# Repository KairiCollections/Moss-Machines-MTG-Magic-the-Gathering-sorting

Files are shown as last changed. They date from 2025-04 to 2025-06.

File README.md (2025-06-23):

# Moss Machine - Open Source Magic: The Gathering - MTG - Sorting & Recognition

<p align="center">
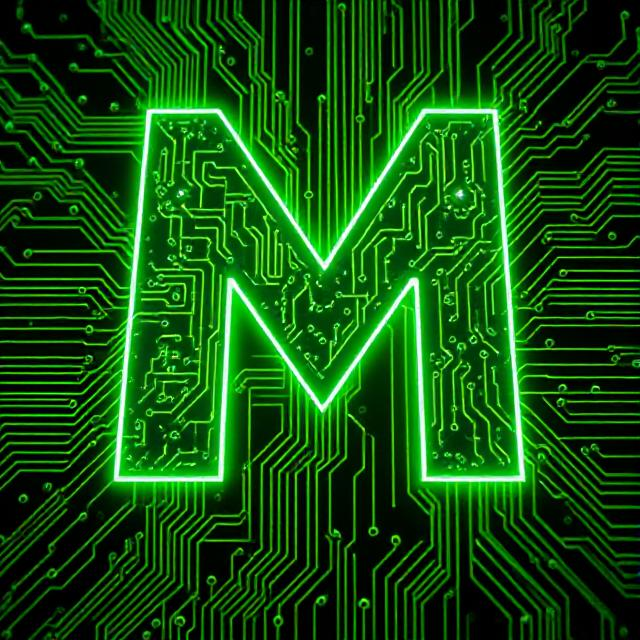
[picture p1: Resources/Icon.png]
  
</p>

Welcome to the Moss Machine project! This open-source initiative provides a comprehensive system for automating the sorting, recognition, and management of Magic: The Gathering (MTG) cards, with potential expansion to other Trading Card Games (TCGs).

---

### Overview

The Moss Machine combines computer vision, machine learning, and hardware integration to create a reliable, customizable card sorting solution. Whether you're a collector, player, or developer, this project offers tools and guidance to build your own automated card sorting system.

---

## Features

- **Open Source & Community Driven**  
  Fully open source code with transparent development. Contributions and modifications are encouraged—please credit the original source when creating derivatives.

- **Versatile Recognition Methods**  
  - Uses OpenCV for precise card detection and perspective correction at any angle.  
  - Employs advanced contour detection for accurate boundaries even in imperfect lighting conditions.  
  - Implements image hashing techniques for quick identification against a database of known card images, including color channel separation (RGB) for improved accuracy.  
  - Integrates Tesseract OCR for secondary verification through text recognition (e.g., card names).

- **Sorting & Organization**  
  - Multiple sorting modes based on card attributes such as color, mana value (CMC), type, set, and market value brackets.  
  - Supports flexible system configurations, including set grouping and custom filters.  
  - Special "buy mode" for evaluating purchase decisions based on price thresholds, helping collectors maintain budgets.

- **Hardware Integration**  
  Designed to interface with physical sorting hardware via serial communication, configurable for different bin layouts and rejection mechanisms.

- **Performance & Logging**  
  - Detailed timing logs for each processing stage.  
  - Robust multiple attempt strategies for reliable name detection and image matching.  
  - Excludes digital-only and promotional sets for focused collection management.

- **Configurable & Extensible**  
  - Centralized configuration files for all settings.  
  - Adjustable thresholds for matching accuracy.  
  - Easy modification of sorting logic and set filters.

- **Technology Stack**  
  - Python: OpenCV, Tesseract OCR, ImageHash, PySerial, YOLO (Ultralytics), Pillow, NumPy, JSON, Scikit-Image  
  - C++: Arduino control and decision-making  

---

## Pictures
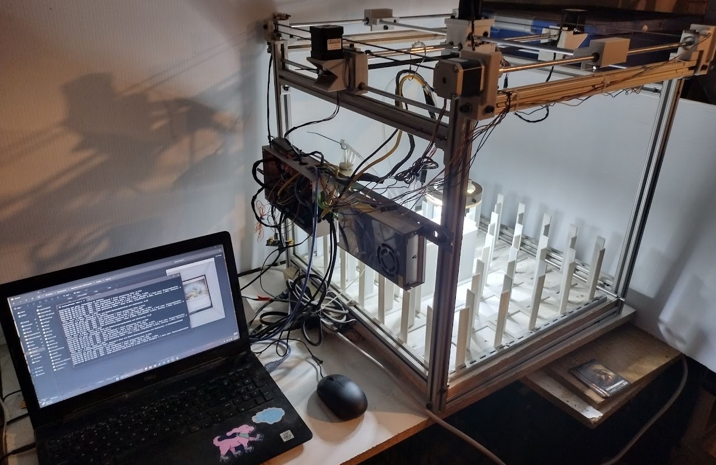
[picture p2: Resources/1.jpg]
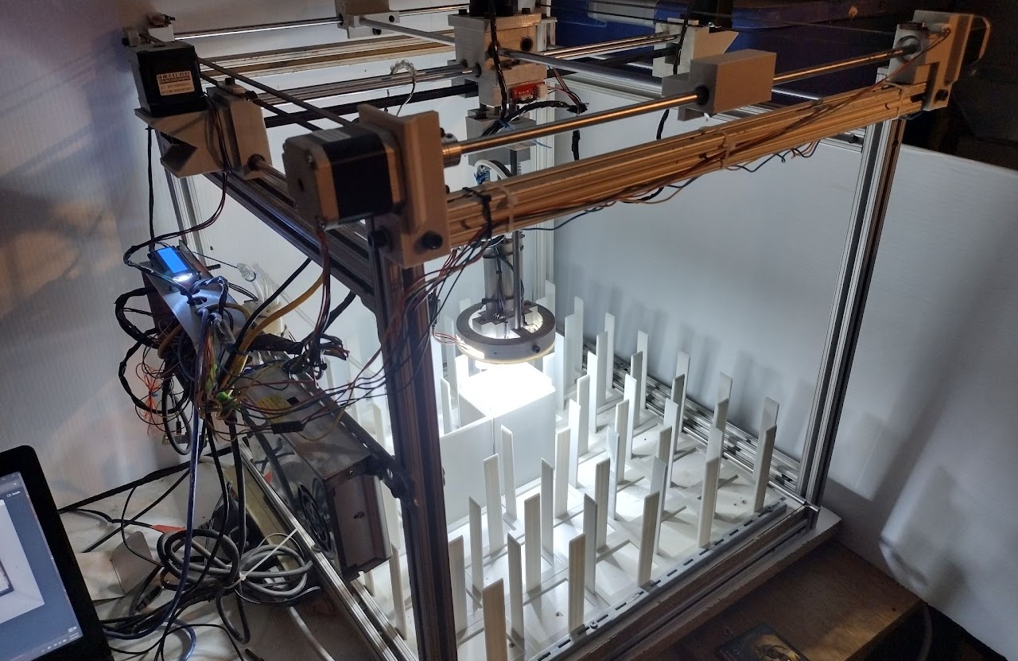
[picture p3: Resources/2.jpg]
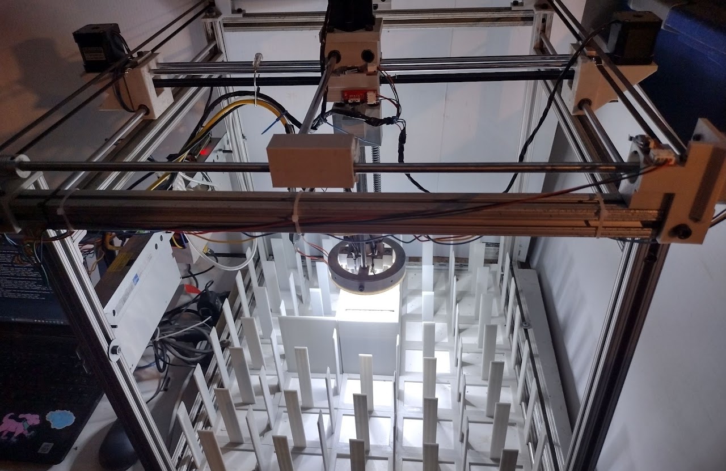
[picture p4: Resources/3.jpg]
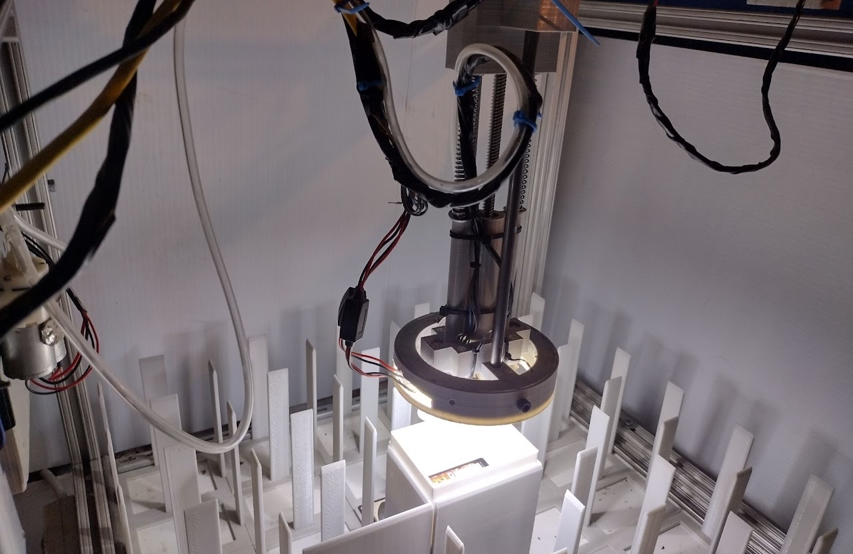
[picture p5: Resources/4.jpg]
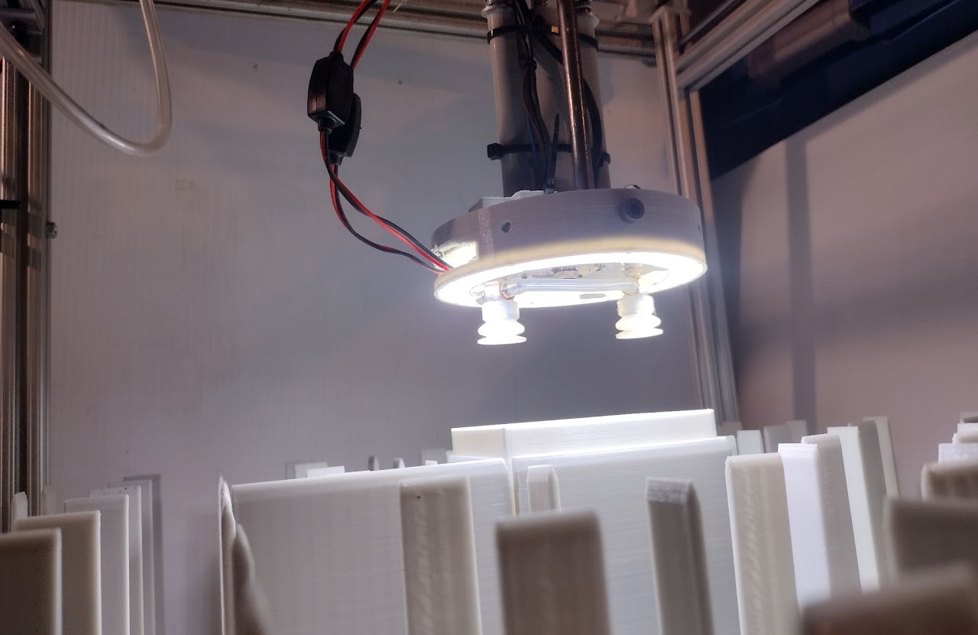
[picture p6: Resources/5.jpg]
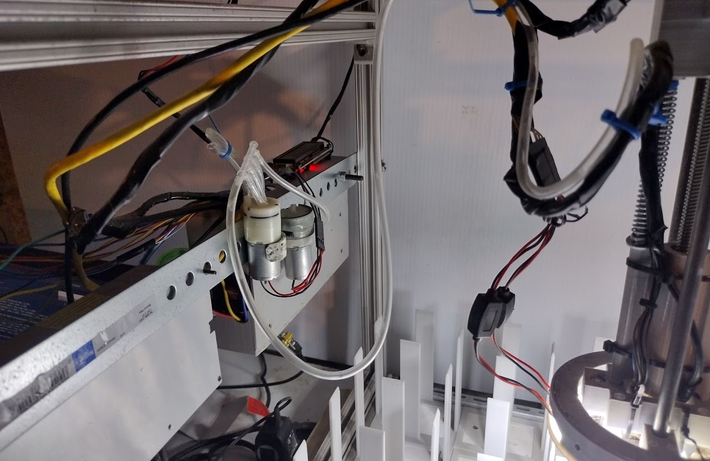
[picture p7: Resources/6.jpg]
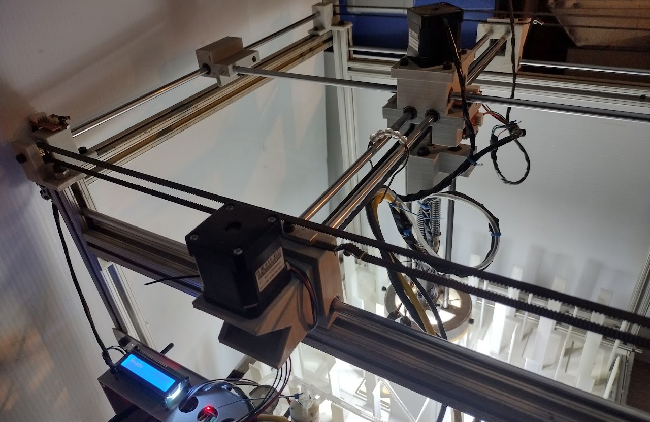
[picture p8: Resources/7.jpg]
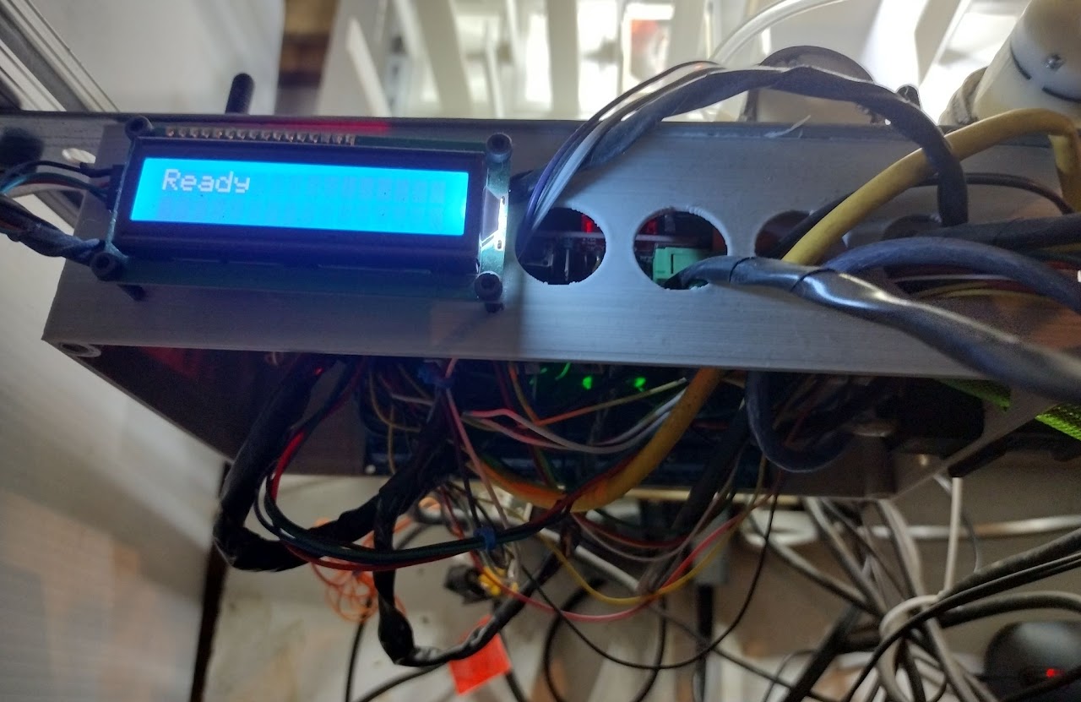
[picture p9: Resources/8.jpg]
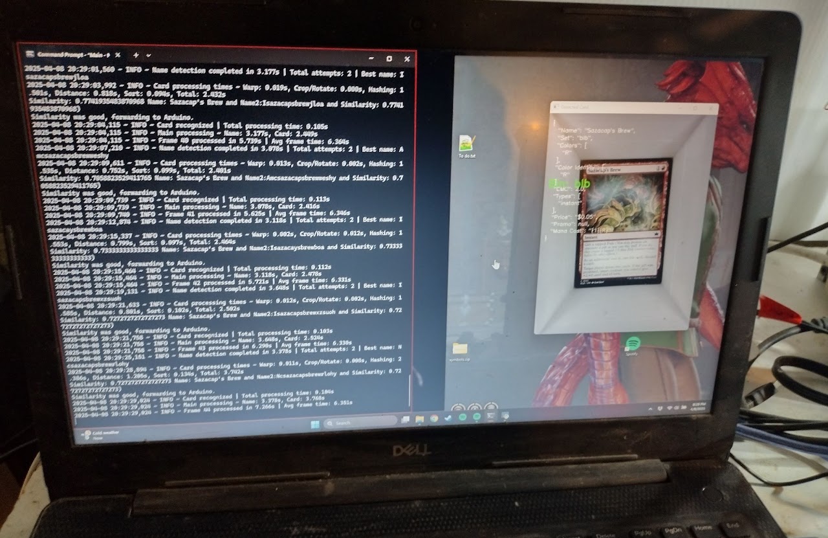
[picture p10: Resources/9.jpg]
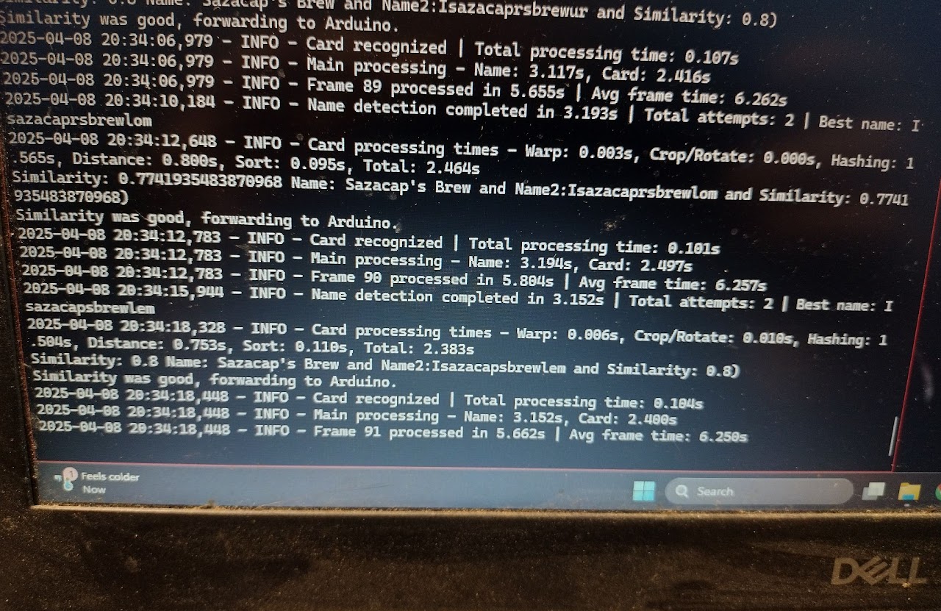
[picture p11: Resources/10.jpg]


---

### Disclaimer

- The project is open source and may evolve significantly over time.  
- All code is thoroughly tested but may require calibration based on your hardware setup.  
- Use caution—never put valuable cards in the machine without testing.  
- If you modify or create your own variations, please credit the original source.

---

## Build Your Own

### Get Started
- All necessary files, including code, 3D print files, and hardware schematics, are available in this repository.
- Follow the detailed instructions within the Discord under #assembly

---

## Legal & Usage Notice

**Disclaimer:**  
This system is intended for hobbyist and educational use. Always test with non-valuable cards first. Handle valuable or rare cards with care—never trust automated sorting in critical scenarios. The project is open source; use at your own risk.

---

## Connect with Us & Follow

| Discord Logo | Reddit Logo | GitHub Logo |
|:---:|:---:|:---:|
| **Join our Discord:**<br>[https://discord.gg/2gNWpV6UjW](https://discord.gg/2gNWpV6UjW) | **Reddit:**<br>[r/MossMachine](https://www.reddit.com/r/MossMachine/) | **Repository:**<br>[GitHub](https://github.com/KairiCollections/Moss-Machine---Magic-the-Gathering-recognition-and-sorting-machine) |

---

## Support
Help keep my motivation and my wife less annoyed with the machine's existence
- Patreon - https://www.patreon.com/KairiCollections
- By me a coffee - https://www.buymeacoffee.com/KairiCollections
- Ko-fi - http://ko-fi.com/kairiskyewillow

Other non-related support:
- https://www.etsy.com/shop/KairiCollections

---

## Acknowledgments & License

This project is licensed under the **Creative Commons Attribution-NonCommercial-ShareAlike 4.0 International License (CC BY-NC-SA 4.0)**.  
Please give credit to the original authors when creating derivatives.

---

**Happy Sorting & Recognizing!**  
*Build smarter, organize better, and enjoy your collection to the fullest!*

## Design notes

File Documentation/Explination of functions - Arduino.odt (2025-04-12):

Moss Machine Arduino code

This code controls an automated card sorting machine that uses stepper motors, relays, suction cups, vacuum pumps and a VL6180X distance sensor to pick up and sort cards into different trays based on input from a python script running on a computer.

Main Components and Functions

Hardware Control

- Stepper motors for X, Y, Z axis movement

- Relay-controlled vacuum system for card pickup/release

- VL6180X time-of-flight distance sensor for card detection

- I2C LCD for status display

- Endstop switches for homing/calibration

Core Functionality

- Receives sorting commands via serial communication

- Moves cards to designated trays based on input

- Tracks card counts per tray

Adjustable Variables and Their Functions

Movement Parameters

const short initial_pickup_distance | Initial Z-axis movement distance for pickup
const short initial_drop_distance | Initial Z-axis movement distance for drop
const short Xcal | X-axis movement multiplier (steps per unit)
const short Ycal | Y-axis movement multiplier (steps per unit)
const short RZM | Z-axis range-to-movement scaling factor

Speed Settings

const short speed | Base movement speed (higher = slower) for X/Y axes
const short zspeed | Z-axis movement speed during pickup
const short zespeed | Z-axis movement speed during return

Thresholds and Limits

const short pickup_threshold | Minimum distance reading to consider card picked up
const short release_threshold | Minimum distance reading to confirm card released
const short HCC | Homing Cycle Count - rehome after this many operations
const short YCourseCorrection | Y-axis correction steps after movement
const short XCourseCorrection | X-axis correction steps after movement
const float timeout | Communication timeout value
const short buffSize | Serial input buffer size

Tray Configuration

short CountArray[35]; | Tracks card count in each tray (indices 1-34 used)
String AssignedTrayValue[35]; | Stores what each tray is assigned to sort

Key Functions Explained

Homemachine()

- Calibrates the machine by moving each axis until endstops are triggered

- Establishes known home position

- Called periodically (based on HCC) to maintain accuracy

pick(short steps, byte Release)

- Handles card pickup and release

- Uses vacuum relays to pick up cards

- Implements retry logic if pickup fails

- Release parameter determines if picking up (0) or releasing (1)

Tray(short var)

- Main sorting function that moves cards to specified tray

- Calculates X/Y coordinates based on tray number

- Manages pickup, movement, and drop sequence

- Updates tray counters

Move4() and Move1()

- Coordinate multi-axis movements

- Control stepper motor direction and step timing

- Implement precise positioning

DetermineAction()

- Parses incoming commands

- Routes to appropriate tray handling based on input

- Supports special commands like calibration

ReadRange()

- Gets distance measurements from VL6180X sensor

- Used to verify card pickup/release

- Also reads ambient light level (Lux)

ForLoop()

- Manages tray assignment logic

- Finds available trays for incoming cards

- Handles overflow conditions

Safety and Error Handling

Endstop Monitoring

- Regularly checks limit switches to prevent over-travel

- Used for homing/calibration
- ***Currently not being used during active operation*** if an error occurs and it “goes off the rails” turn off the machine. It will make noise but it will not damage anything. This will be enabled later

Sensor Error Detection

- Comprehensive VL6180X error status checking

- LCD feedback for sensor issues

Timeout Handling

- Automatic overflow tray routing if no commands received

Pickup Retry Logic

- Multiple attempts if card pickup fails

- Machine stop if persistent failures

Overflow Protection

- Stops machine if overflow tray reaches capacity (375 cards)

Communication Protocol

- Uses serial communication with start/end markers (< and >)

- Simple command structure (e.g., "tray1", "RejectCard")

- Status messages sent back to host ("<Arduino is ready>")

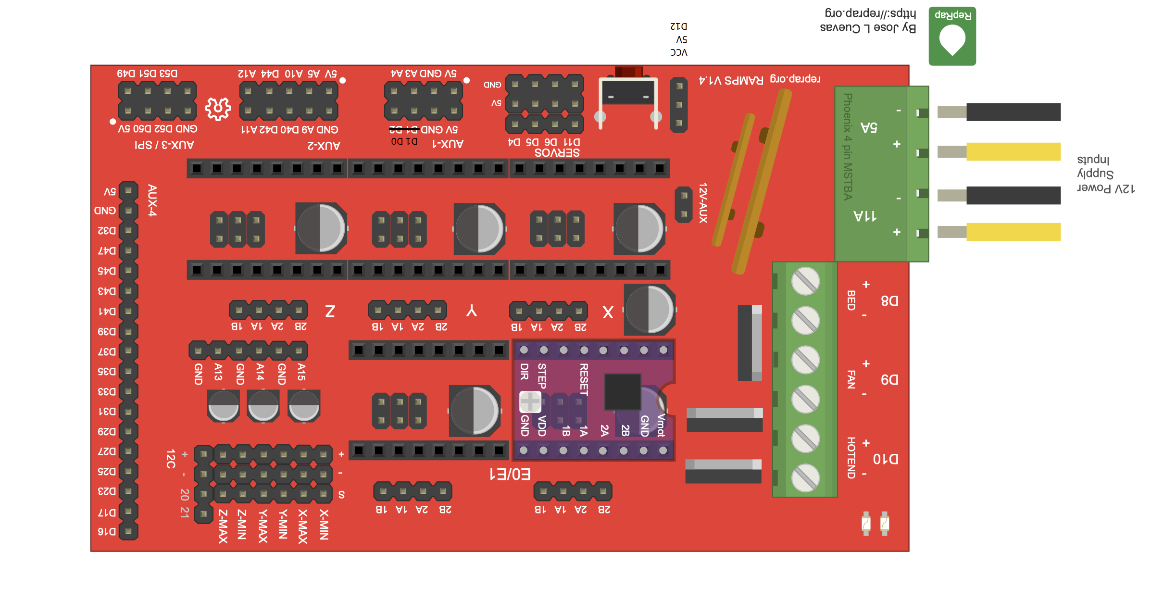
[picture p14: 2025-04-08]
Blueprints and diagrams/Ramps 1.4 Pinout.png

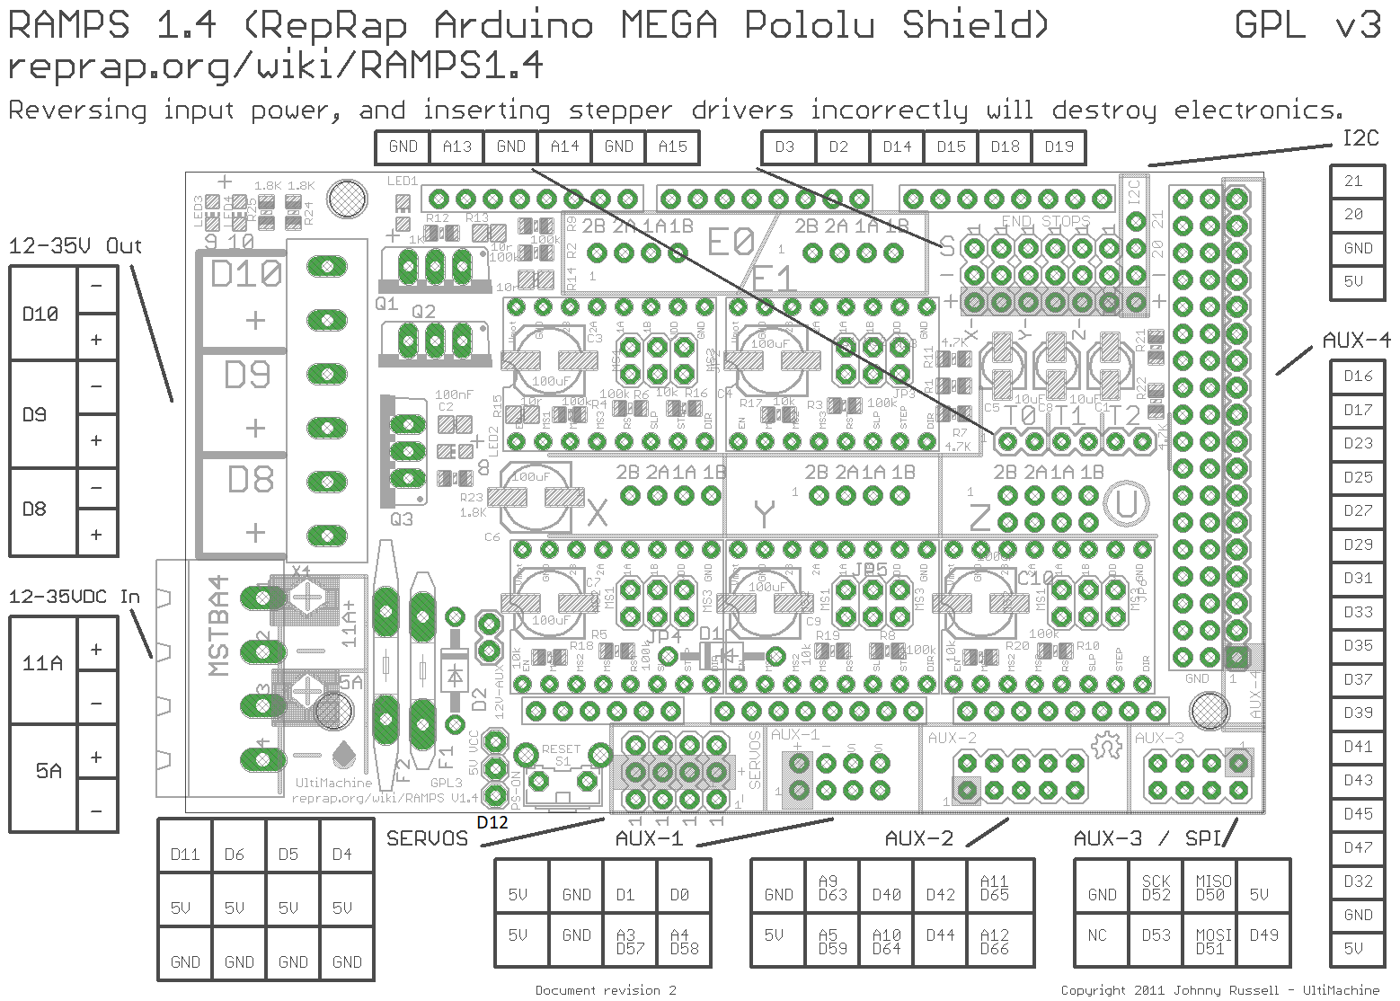
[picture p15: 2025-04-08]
Blueprints and diagrams/Ramps 1.4 Schematic 1.png

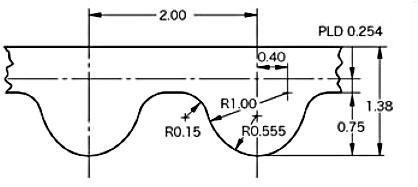
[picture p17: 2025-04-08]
Blueprints and diagrams/GT2 Belt.jpg

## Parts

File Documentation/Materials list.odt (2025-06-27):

Magic the Gathering

sorting machine materials

(If link is dead let me know)
Obviously these are just link recommendations, if you find a better deal go for it!

2525 Frame

Items | URL | Quantity
25x25x550mm Aluminum t-slot bar | https://www.amazon.com/IXGNIJ-Aluminum-Extrusion-25mmx25mm-European/dp/B0CR5P392H/ Cut to lengths (Trying to find a cheaper source, the 2020 frame is overall cheaper by about $90 on the complete build) | 6
25x25x500mm Aluminum t-slot bar | | 8
25x25 t-slot corner brackets | https://www.amazon.com/Connector-Aluminum-Extrusion-Bracket-Extruded/dp/B0B8H43B8X/ | 1

2020 Frame

Items | URL | Quantity
20x20x550mm Aluminum t-slot bar | https://s.click.aliexpress.com/e/_ooVn7JZ | 6
20x20x500mm Aluminum t-slot bar | | 8
20x20 corner brackets | https://s.click.aliexpress.com/e/_opvcbMQ | 1

Components

Items | URL | Quantity
M6 t slot nut (lot of 20) should work for either frame | https://s.click.aliexpress.com/e/_opiADM7 | 1
550mm x 8mm milled steel rods | https://www.amazon.com/550mm-Linear-Motion-Printer-Machine/dp/B09P87GC3X/ or https://s.click.aliexpress.com/e/_okMx702 or https://www.amazon.com/dp/B0B2LPDSMC/ | 6 rods total
2x 500mm x 8mm milled steel rods | | 2 rods total
2x 300mm x 8mm milled steel rods | | 2 rods total
12v 20A Power supply | https://s.click.aliexpress.com/e/_on92Pan | 1
12v Halo lights: 100mm and 110mm (white, comes in packs of 2 so you will have extras) | https://s.click.aliexpress.com/e/_omvoQvM | 1 each
Ardiuno Mega 2560 kit (Package B) | https://s.click.aliexpress.com/e/_oCAmKlH | 1
LCD1602 Blue I2C or LCD1602 Green I2C | https://s.click.aliexpress.com/e/_ol1EtsT | 1
Pulleys (5PCS, 20T W6 B5) | https://s.click.aliexpress.com/e/_oEcsqdb | 1
More pulleys (20T W6 B5) | https://s.click.aliexpress.com/e/_omv5y17 | 2
Belt clamps (lot of 3) | https://s.click.aliexpress.com/e/_omXSal3 | 1
6mm belt (5 meters) | https://s.click.aliexpress.com/e/_olDFNsd | 1
Belt tensioner springs | https://s.click.aliexpress.com/e/_oELpuTn
Time of Flight sensor (TOF050C) | https://s.click.aliexpress.com/e/_ontJu63 | 1
Power switch | https://s.click.aliexpress.com/e/_olikwcJ | 1
8MP USB camera (2 meter cable) | https://s.click.aliexpress.com/e/_olqvzqJ | 1
8mm screw rod - Pitch 2mm Lead 8mm, 300mm | https://s.click.aliexpress.com/e/_onu2dUo | 1
Endstops (you might break a couple during assembly, best to have extras) | https://s.click.aliexpress.com/e/_oljfq7t | 1
8mm bearings (LM8UU 10 pack) | https://s.click.aliexpress.com/e/_okaOZNY | 3
5mm to 8mm couplers | https://s.click.aliexpress.com/e/_oF5uLz0 | 3
Suction cups (Package 1) | https://s.click.aliexpress.com/e/_on9q31Y | 2
Vacuum pumps (300g option) | https://s.click.aliexpress.com/e/_oke1dk3 | 2
Hose splitter 2.4mm | https://s.click.aliexpress.com/e/_oEc8Vw2 | 1
Air line
Motors 17HS19-2004S1 – These are particularly strong motors for their size but rather they be strong vs weak (I used 42bhh48-151k-24b but a same size similar torque will work fine) | https://s.click.aliexpress.com/e/_onv5IFN | Need 5 (comes 3 per lot, will have 1 extra replacement motor
Hillman 1-3/8-in x 4-ft Interior/Exterior Zinc-Plated Steel Perforated (Need atleast 4 feet) | https://www.lowes.com/pd/Hillman-4-ft-x-1-375-in-Steel-Perforated/3059255 | 1
Hillman 10¼ in Zinc Gate Extension Spring 0.44 x 10¼ x 0.04 (11.10mm x 260.35mm x 1.05mm) | Lowes - Buy in store, website is confusing. UPC 008236801149 | 1
M6 thread x M8 shoulder x 100mm shoulder bolts | https://s.click.aliexpress.com/e/_oDGH8Bs | 2
M8x16x1 20 washers | https://s.click.aliexpress.com/e/_ole4eru | 1 lot (only need 2 of them)
Wires 18g wire (yellow and black) Can steal from an old PC power supply Bulk thinner wire (I mainly used recycled Ethernet and USB cables, lots of colors, nothing hair thin) but 26 awg will work fine | Recycle if possible but if not https://s.click.aliexpress.com/e/_ooCR0iT for both | A lot
Bolts, screws and nuts: 3mm x 10mm – 13 3mm x 15mm – 20 3mm x 20mm – 3 4mm x 10mm – 3 5mm x 15mm – 4 5mm x 30mm – 2 5mm x 5mm set screws – 6 6mm x 10mm – 12 6mm x 15mm – 2 6mm x 30mm – 4 6mm x 50mm – 4 #8 2-inch screws – 4 | | ?
M5 x 10mm tapered wood screws (48) | https://s.click.aliexpress.com/e/_oB0LquT | 5
Wood square – 550mm x 500mm x 25mm
Single shower curtain ring | Dollar tree | 1
Tip ties
Electrical tape or a wire management coil

3d printed stuff

Items | In GitHub | Quantity
Tray - 2 sides Tray - 3 sides W Tray - 3 sides T Tray - All sides Tray stabilizers: Tray mount - Middle Tray mount - Side Tray mount - Corners | | 24 6 4 1 24 20 4
X1, X2, X3, X4, Z1, Z2, Z3, Z4 (this model is duplicated to be 130mm long because of the shorter shoulder bolts. If you managed to get the 140mm bolts before the link died print the 90mm version), Z5, Light mount 1 and 2, Power switch case (2 pieces) Stabilizer / Y axis traveler | | 1 of each 2 of each
If using the 2020 frame: 2.5mm spacer 5mm spacer OR (M6x20x2.5mm 5 per lot) | https://s.click.aliexpress.com/e/_onpoScr | 24 4 7 lots (Need 32 washers)

Optional Substitutions

Items | URL | Replaces | Quantity
DIN rail main power supply (NDR-240-12V 20A) | https://s.click.aliexpress.com/e/_oETsD6e | 12v 20A Power supply | 1
DIN rail (50cm) | https://s.click.aliexpress.com/e/_o2B4oyA | Hillman 1-3/8-in x 4-ft Interior/Exterior Zinc-Plated Steel Perforated | 1
DIN rail mounts - 3d print - 3 files | In GitHub

Tools

Items | URL | Quantity
Volt meter (Needed to calibrate the main power supply to 12 volts) | (https://s.click.aliexpress.com/e/_olln5Pv) | 1
Dupont kit (SN-28B AND 1550PCS) | https://s.click.aliexpress.com/e/_oBtivTU | 1
Metric Allen wrenches (11Pcs Metric short) | (https://s.click.aliexpress.com/e/_op3MiA7) | 1
Small screwdriver kit | (https://s.click.aliexpress.com/e/_olUUvgb) | 1
Pliers | (https://s.click.aliexpress.com/e/_opsQM6L) | 1
Mini hammer (You don’t need a big smashy smashy hammer) | | 1
Drill | | 1
Drill bit set | | 1
6mm tap | Probably best to not buy from Aliexpress on this, get one local and high quality. You don’t want a cheap one to snap in the frame -_- | 1
Small piece of wood (2” square ish) for TAPPING bearings into 3d prints instead of hammering the bearing directly | | 1

Patreon - https://www.patreon.com/KairiCollections

By me a coffee - https://www.buymeacoffee.com/KairiCollections

Ko-fi - http://ko-fi.com/kairiskyewillow

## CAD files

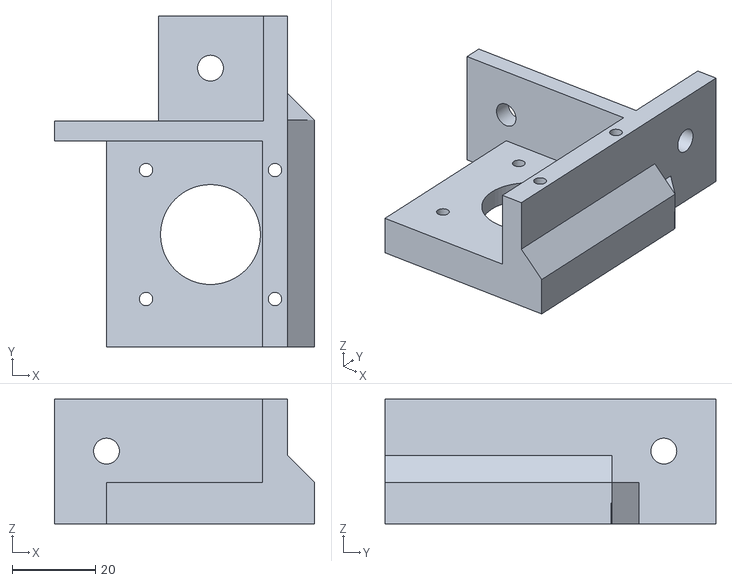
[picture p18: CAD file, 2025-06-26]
3D print/Axis/Axis - X/X motor mount 1.stl
62.5 x 79.5 x 30.0

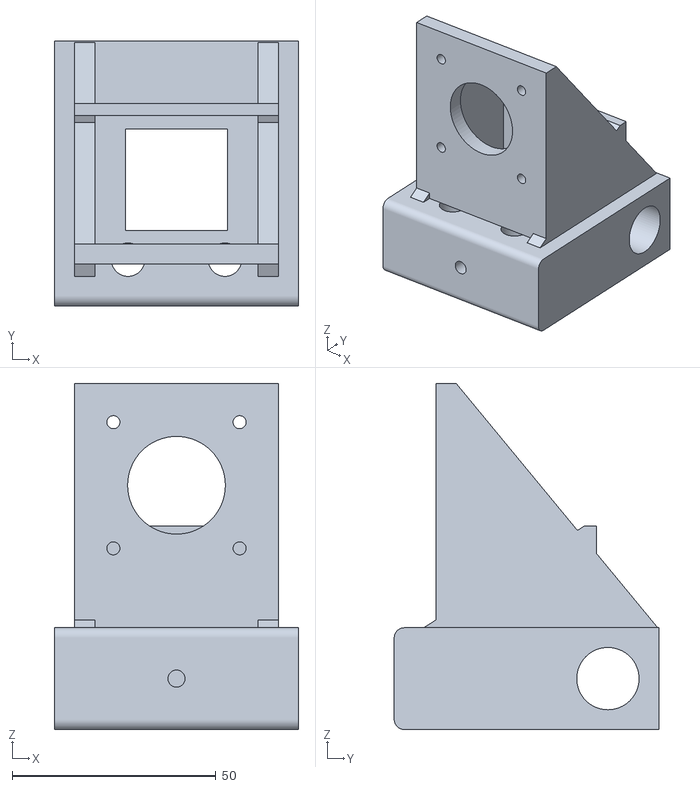
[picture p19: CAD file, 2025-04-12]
3D print/Axis/Axis - Y/Y - motor mount (Print 2).stl
60.0 x 65.0 x 85.0

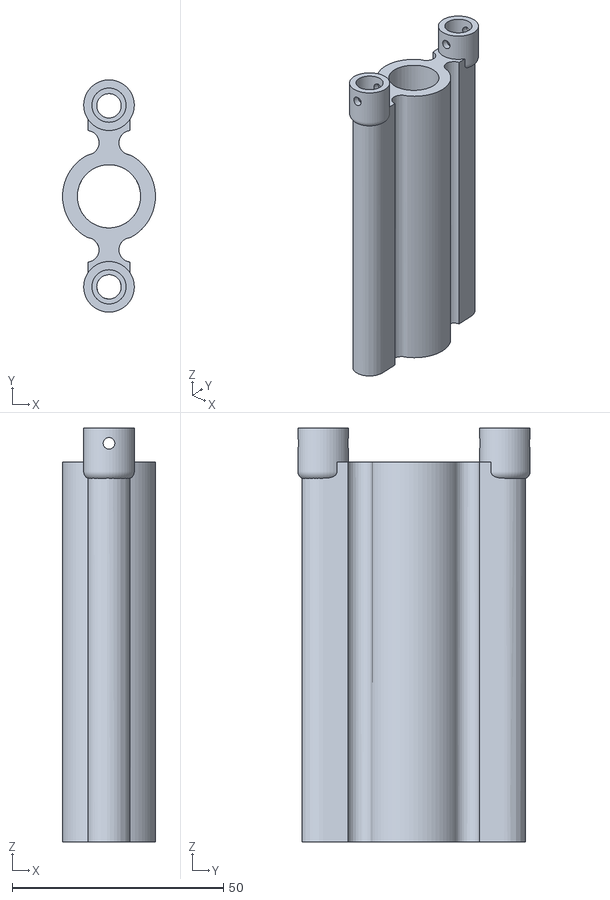
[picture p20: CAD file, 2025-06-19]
3D print/Axis/Axis - Z/Z4 - Extension - Option 2.stl
22.0 x 55.0 x 98.0

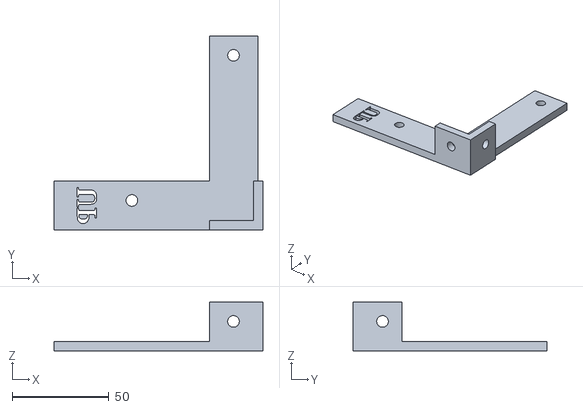
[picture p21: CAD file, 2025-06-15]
3D print/Drill guides/2020/Drill guide 1.stl
108.0 x 100.2 x 25.2

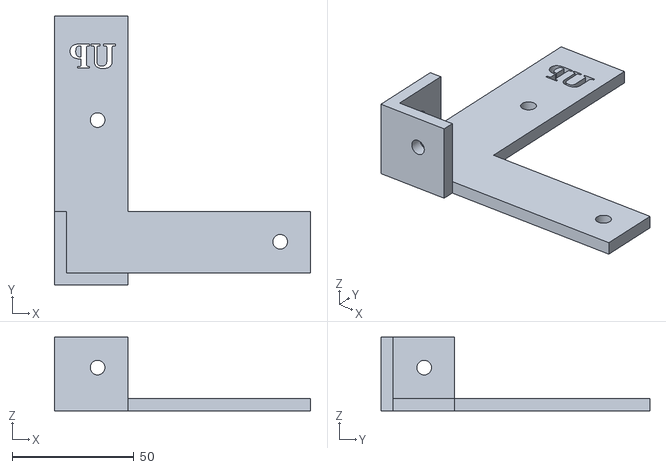
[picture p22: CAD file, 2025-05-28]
3D print/Drill guides/2525/Drill guide 2.stl
105.2 x 110.5 x 30.2

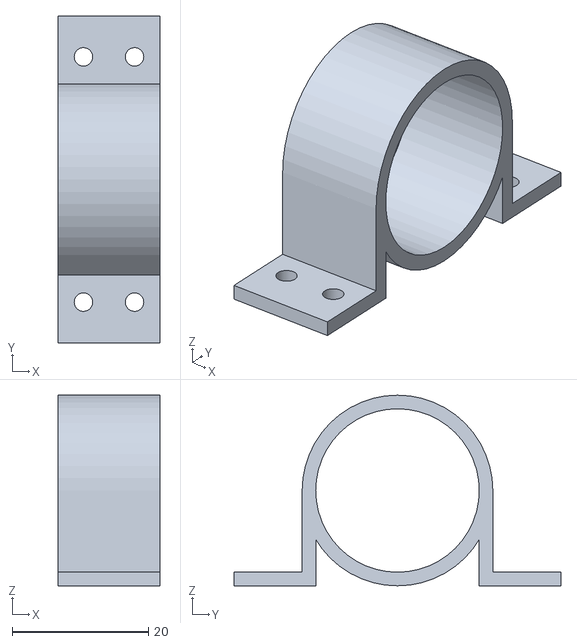
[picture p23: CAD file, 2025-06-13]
3D print/Electrical/Din rail options/Vacuum mount.stl
15.0 x 48.0 x 28.0

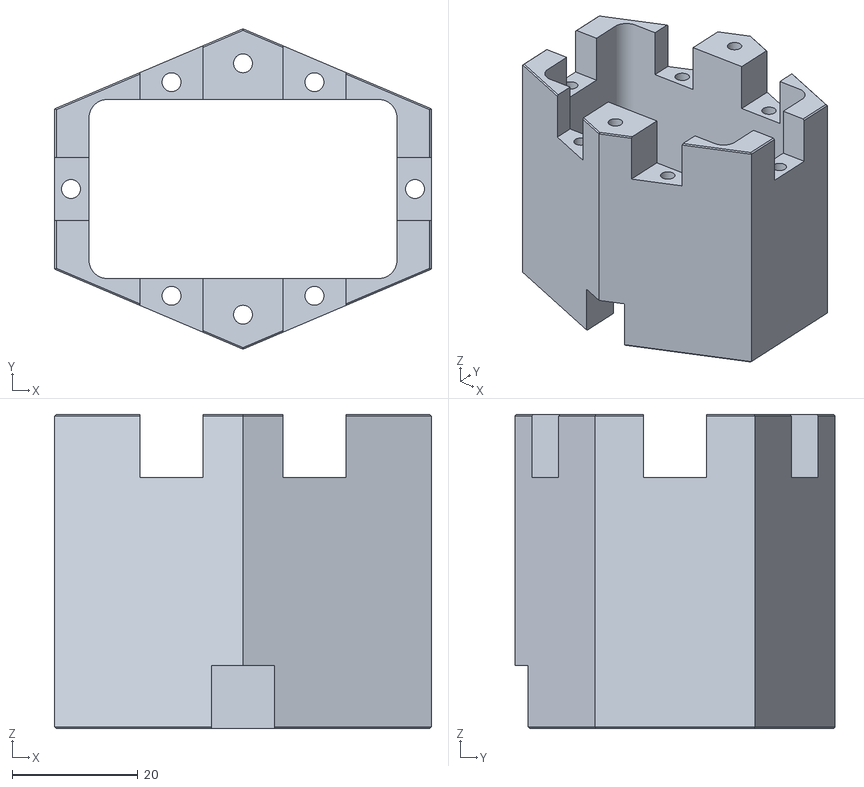
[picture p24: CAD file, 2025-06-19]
3D print/Electrical/Electrical box/Power switch case.stl
60.0 x 51.0 x 50.0

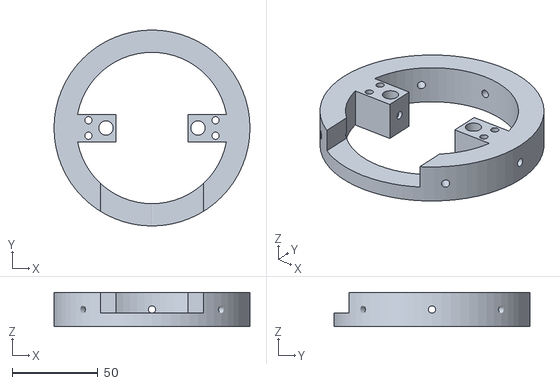
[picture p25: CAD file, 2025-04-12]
3D print/Electrical/Light/Light mount.stl
114.0 x 114.0 x 20.0

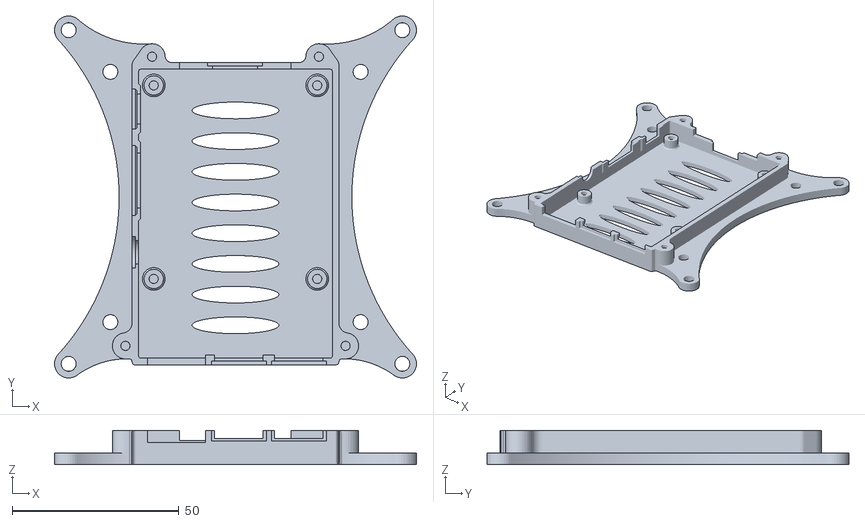
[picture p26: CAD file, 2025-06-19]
3D print/Electrical/Raspberry Pi/RPI bottom.stl
108.5 x 108.5 x 10.3

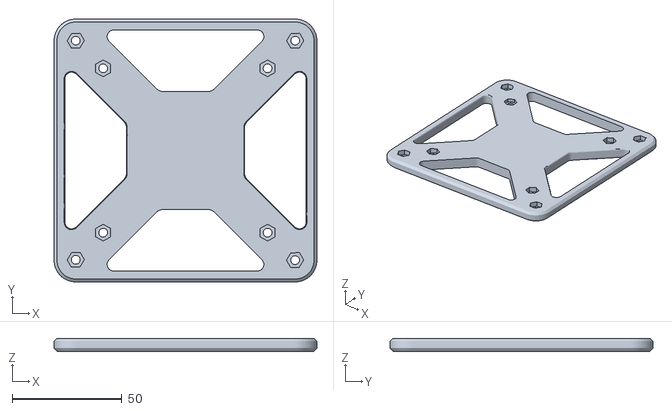
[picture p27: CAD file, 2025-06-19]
3D print/Electrical/Touch screen/VESA-75-100-remix-v1.1.stl
120.0 x 120.0 x 6.14

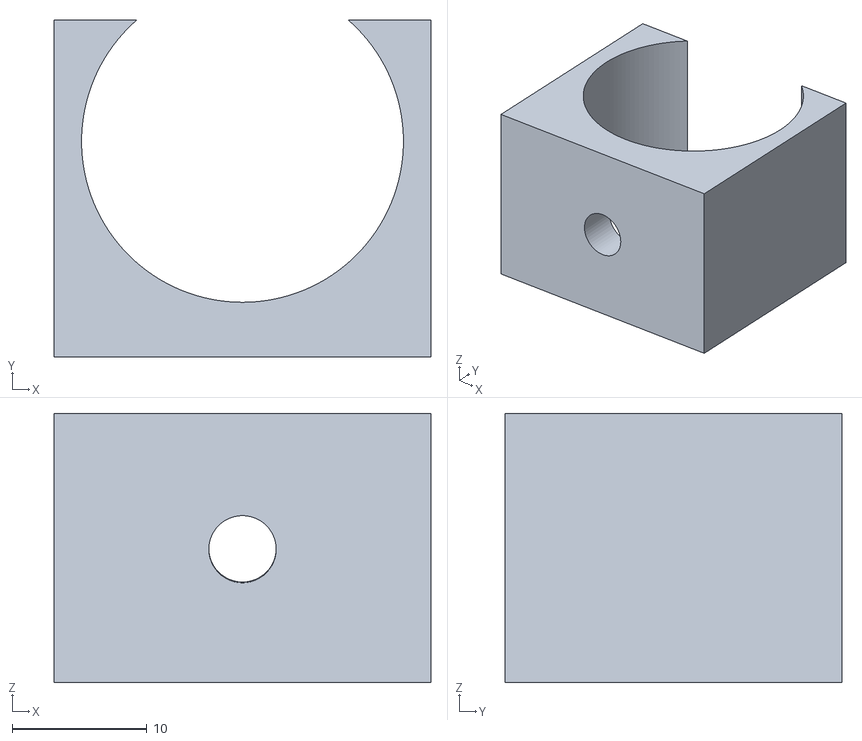
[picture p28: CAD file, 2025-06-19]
3D print/Electrical/Vacuum holders/Vacuum holder - Option 2.stl
28.0 x 25.0 x 20.0

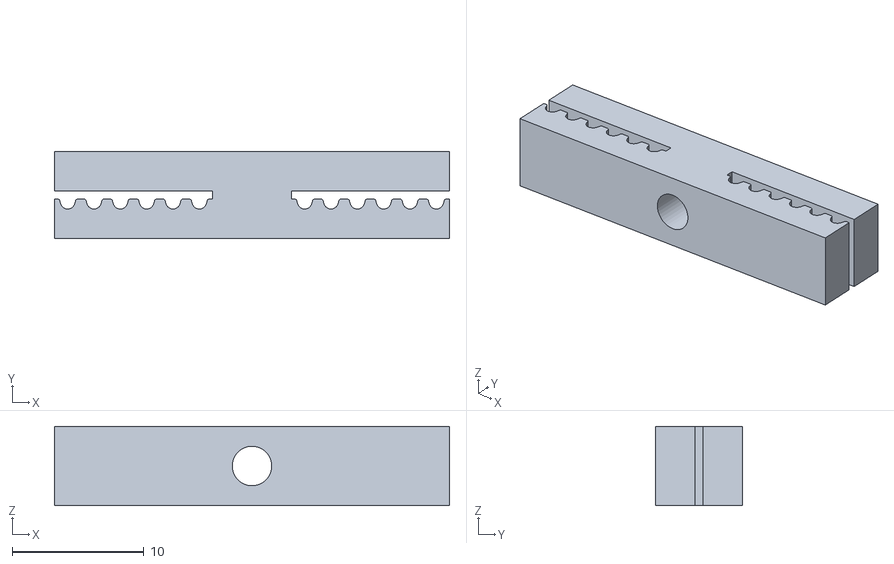
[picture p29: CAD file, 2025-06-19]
3D print/Optional (print instead of buying hardware)/GT2 clamp (print 3).STL
30.0 x 6.63 x 6.00

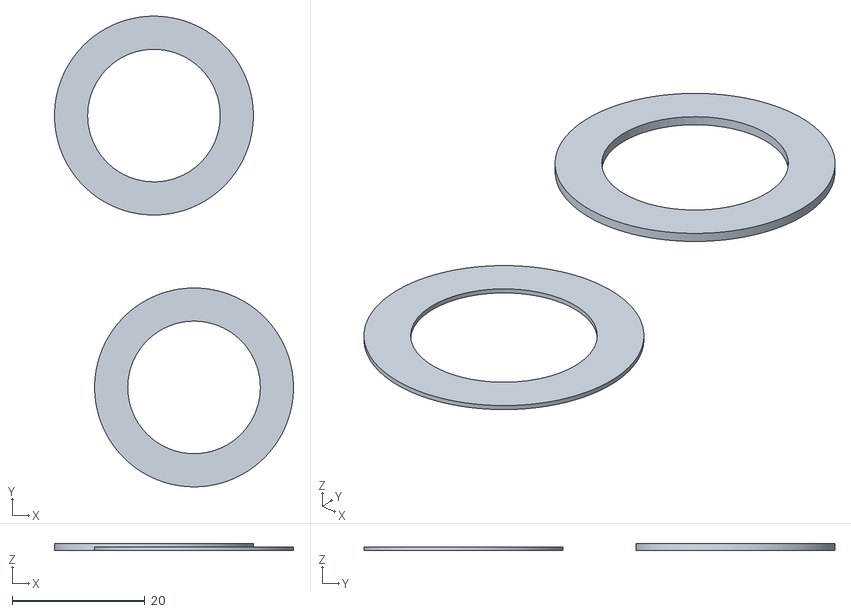
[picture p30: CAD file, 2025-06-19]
3D print/Spacers and shims/shim.stl
36.1 x 71.0 x 1.00

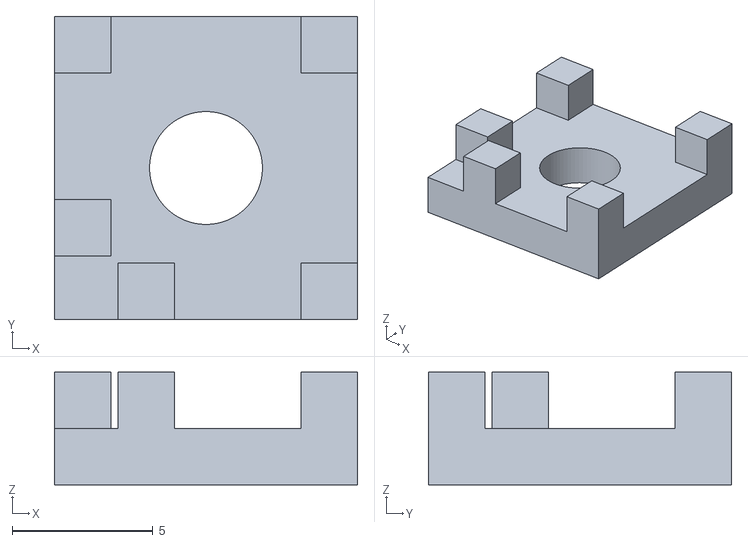
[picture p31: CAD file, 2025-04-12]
3D print/Trays/Tray mount - Corners (Print 4).stl
10.8 x 10.8 x 4.00

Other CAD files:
3D print/Axis/Axis - X/X motor mount 2.stl
3D print/Axis/Axis - Y/Y - stabilizer (Print 2).stl
3D print/Axis/Axis - Z/Z4 - Extension - Option 3 (130mm version).stl
3D print/Drill guides/2020/Drill guide 3.stl
3D print/Axis/Axis - X/X1 - Belt.stl
3D print/Axis/Axis - X/X2 - Belt.stl
3D print/Axis/Axis - Z/Z1 - Motor mount.stl
3D print/Axis/Axis - Z/Z2 - XY Traveler.stl
3D print/Axis/Axis - Z/Z3 - Z Traveler.stl
3D print/Axis/Axis - Z/Z4 - Extension - Option 1.stl
3D print/Axis/Axis - Z/Z5 - Mount all accessories.stl
3D print/Drill guides/2020/Drill guide 2.stl
3D print/Drill guides/2020/Drill guide 4.stl
3D print/Drill guides/2525/Drill guide 1.stl
3D print/Drill guides/2525/Drill guide 3.stl
3D print/Drill guides/2525/Drill guide 4.stl
3D print/Electrical/Din rail options/Power switch mount.stl
3D print/Electrical/Din rail options/Universal din rail mount.stl
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

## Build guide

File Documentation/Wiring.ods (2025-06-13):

Component | + | - | Signal 1 | Signal 2 | Other/note
TOF050C | 5V | GND | SDA to Arduino D20 | SCL to Arduino D21 | Solder pins, INT and SHUT are not used
LCD | 5V | GND | SDA to Ramps D20 | SCL to Ramps D21
Endstop X MIN | 3 | GND | C to S
Endstop Y MIN | 14 | GND | C to S
Endstop Z MIN | 18 | GND | C to S
Endstop X MAX | 2 | GND | C to S
Endstop Y MAX | 15 | GND | C to S
Endstop Z MAX | 19 | GND | C to S
Ring lights | 12v aux + | 12V aux -
Vacuum 1 | D9+ | D9-
Vacuum 2 | D10+ | D10-
Arduino Mega 2560 |  |  |  |  | USB to PC
Camera |  |  |  |  | USB to PC
Motor X1 |  |  |  |  | Ramps X
Motor X2 |  |  |  |  | Ramps E0
Motor Y1 |  |  |  |  | Ramps Y
Motor Y2 |  |  |  |  | Ramps E1
Motor Z |  |  |  |  | Ramps Z
Other considerations:
Power switch | RED to PS AC LIVE | BLUE to AC PS NEUTRAL | YELLOW TO AC PS GND | <------------ | No not mess this up
Power supply outputs | 12V+ to Ramps+ (x2) | 12V- to Ramps- (x2)
Pump 1 | Pump output no hose | Pump vacuum side gets T'd off to Pump 2 output and suction cups
Pump 2 | Pump output already T’d off | Pump vacuum side gets a 5 inch hose that is clamped shut half way (I folded it over with zip ties but you could use a check valve for an aquarium air line with the arrow facing toward the pump)
 | This allows the 1st vacuum to suck up the card without aggressively drawing air through vacuum 2 but allows vacuum 2 to draw a slight amount of air from the kinked hose to release the card
Surge protector | Plug power into a surge protector

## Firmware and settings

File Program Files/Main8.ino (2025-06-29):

#include <LiquidCrystal_I2C.h>
#include <Stepper.h>
#include <Wire.h>
#include "Adafruit_VL6180X.h"

//Pin Definitions for hardware control
enum Pins { 
    Zmin = 18, Xmin = 3, Ymin = 14, Xmax = 2, Ymax = 15, Zmax = 19, //Endstops
    Lights = 8, Vacuum1 = 9, Vacuum2 = 10, //Vacuums: Pickup/Release respectively
    Xenable = 38, Yenable = 56, Zenable = 62, E0enable = 24, E1enable = 30, //Motors
    Xstep = 54, Ystep = 60, Zstep = 46, E0step = 26, E1step = 36, //Stepper Controls
    Xdir = 55, Ydir = 61, Zdir = 48, E0dir = 28, E1dir = 34 //Directions
};

//Initialize sensor and display objects
Adafruit_VL6180X vl = Adafruit_VL6180X();  //VL6180X distance sensor object
LiquidCrystal_I2C lcd(0x27, 16, 2);        //LCD for user feedback

//Flags and control variables
boolean newData = false, readInProgress = false, newDataFromPC = false;
byte bytesRecvd = 0, PickupRetry;
const byte numChars = 64, buffSize = 40;                                               //Buffer sizes for serial communication
const char startMarker = '<', endMarker = '>';                                         //Start/End markers for data communication
char inputBuffer[buffSize], messageFromPC[buffSize] = { 0 }, receivedChars[numChars];  //Buffers for data

//Timers and counters
float timeoutcount = 0;
const float timeout = 10;

//Coordinates and distance tracking arrays
const char* MatchingValues[] = {"RejectCard", "tray1", "tray7", "tray14", "tray18","tray25", "tray26", "tray27", "tray28", "tray29", "tray30", "tray31", "tray32"};
const int loopStart[] = {33, 1, 7, 14, 18, 25, 26, 27, 28, 29, 30, 31, 32};
const int loopEnd[] = {33, 6, 13, 17, 24, 25, 26, 27, 28, 29, 30, 31, 32};
boolean match = 0;
const int xOffsets[6] = {-3, -2, -1, 1, 2, 3}; const int yOffsets[4] = {-2, -1, 1, 2}; //Arrays for X/Y coordinate movements
const short X[6][5]={{31,27,21,28,32},{23,11,9,12,24},{17,5,1,6,18},{19,7,2,8,20},{25,13,10,14,26},{33,29,22,30,34}}; //Array for X trays
const short Y[4][7]={{32,24,18,16,20,26,34},{28,12,6,4,8,14,30},{27,11,5,3,7,13,29},{31,23,17,15,19,25,33}}; //Array for Y trays
short CountArray[35], upcount; //Array is for keeping track of how many cards have been moved to each tray
String AssignedTrayValue[35], Tempval1; //Array for keeping try of tray assignments
uint8_t range[6]; //Range readings from VL6180X sensor

//Endstop tracking variables (limits of movement for each axis)
byte X_ENDSTOP_MIN, Y_ENDSTOP_MIN, Z_ENDSTOP_MIN, X_ENDSTOP_MAX, Y_ENDSTOP_MAX, Z_ENDSTOP_MAX;

//Movement parameters (calibration and speed settings)
const short initial_pickup_distance = 6000, initial_drop_distance = 4000;  //Intial movement distances
const short Xcal = 350, Ycal = 475, Zcal = 140;                            //Movement multipliers
const short speed = 700, zspeed = 75, zespeed = 120;                       //Movement speed (Higher number=slower speed)
const short pickup_threshold = 40, release_threshold = 40;                 //Thresholds for pickup/release conditions
const short HCC = 10, YCourseCorrection = 1, XCourseCorrection = 0;        //Cycles until rehome and course correction variables

void setup() {
  byte pins[] = { Xstep, Ystep, Zstep, E0step, E1step, Xdir, Ydir, Zdir, E0dir, E1dir, Xenable, Yenable, Zenable, E0enable, E1enable, Vacuum1, Vacuum2, Lights};
  for (byte pin : pins) { pinMode(pin, OUTPUT); }  //Set all pins as outputs
  byte lowPins[] = { Xenable, Yenable, Zenable, E0enable, E1enable, Vacuum1, Vacuum2};
  for (byte pin : lowPins) { digitalWrite(pin, LOW); }    //Disable motors initially

  Serial.begin(9600);                        //Begin serial connection
  digitalWrite(8, HIGH);                     //Turn on lights
  digitalWrite(13, HIGH);                    //Turn on the onboard LED for debugging
  while (!Serial) { delay(10); }             //Wait for serial to be ready
  Serial.println("Adafruit VL6180x test!");  //Print sensor initialization message
  while (!vl.begin()) {
    Serial.println("Failed to find sensor");
    PrintLCD("Failed to find ", "ToF sensor"); //Display error on LCD if sensor not found
    delay(1000);
  }  
  Serial.println("Sensor found!");PrintLCD("ToF sensor", "found");
  Homemachine(); //Call Homemachine to calibrate the system
  delay(100);Serial.println("<Arduino is ready>");
}

void loop() {
  uint8_t status = vl.readRangeStatus();
  if (AssignedTrayValue[34] != "OverflowTray") {AssignedTrayValue[34] = "OverflowTray";} //Assign some initial tray values that are reserved
  if (AssignedTrayValue[33] != "RejectCard") {AssignedTrayValue[33] = "RejectCard";}
  getDataFromPC(); //Retrieve data from PC

  //Check sensor error status and handle errors accordingly
  if (status == VL6180X_ERROR_NONE) {ReadRange(1); Serial.print("Range: "); Serial.println((range[0] + range[1]) / 2);
  } else {PrintLCD("ToF: No range", " ");}
  switch (status) { //Various errors that can happen with the range sensor
    case VL6180X_ERROR_SYSERR_1 ... VL6180X_ERROR_SYSERR_5: Serial.println("System error"); break;
    case VL6180X_ERROR_ECEFAIL: Serial.println("ECE failure"); PrintLCD("ECE failure", " ");break;
    case VL6180X_ERROR_NOCONVERGE: Serial.println("No convergence"); PrintLCD("No convergence", " "); break;
    case VL6180X_ERROR_RANGEIGNORE: Serial.println("Ignoring range"); PrintLCD("Ignoring range", " "); break;
    case VL6180X_ERROR_SNR: Serial.println("Signal/Noise error"); PrintLCD("Signal/Noise", "error"); break;
    case VL6180X_ERROR_RAWUFLOW: Serial.println("Raw reading underflow"); PrintLCD("Raw reading", "underflow"); break;
    case VL6180X_ERROR_RAWOFLOW: Serial.println("Raw reading overflow"); PrintLCD("Raw reading", "overflow"); break;
    case VL6180X_ERROR_RANGEUFLOW: Serial.println("Range reading underflow"); PrintLCD("Range reading", "underflow"); break;
    case VL6180X_ERROR_RANGEOFLOW: Serial.println("Range reading overflow"); PrintLCD("Range reading", "overflow"); break;
    default: break;
  }
  lcd.init();lcd.backlight();lcd.setCursor(0, 0); //Initialize LCD and turn on the backlight
  ReadEndstops(); //Read endstop values 
  //if(Y_ENDSTOP_MIN==0||Z_ENDSTOP_MIN==0||X_ENDSTOP_MAX==0){PrintLCD("Endstop reached"," ");STOP==1;delay(100);}
  PrintLCD("Ready", " "); //Display "Ready" message on LCD 
  Tempval1 = Serial.readString();delay(10); //read any available data from the serial buffer
  if (Tempval1 != "") {
    PrintLCD("Received: ", Tempval1); //Display the received data on the LCD
    ReadRange(1);DetermineAction(); //Decide what action to take based on received data
    Serial.println("<Arduino is ready>");
    timeoutcount = 0; //Reset timeout counter
  }  
  //timeoutcount++;if(timeoutcount>=timeout){Tray(34);Serial.println("<Arduino is ready>");timeoutcount=0;}
  //Serial.println(timeoutcount);

  //Reset flags
  Tempval1 = "";messageFromPC == "";bytesRecvd == 0;newData = false;readInProgress = false;newDataFromPC = false;
}  

void getDataFromPC() {
  if (Serial.available() > 0) {
    char x = Serial.read();  //Read incoming character
    if (x == endMarker) { //End marker received
      readInProgress = false;
      newDataFromPC = true;
      inputBuffer[bytesRecvd] = 0; //null terminate input buffer 
      parseData(); //parse the received data
    }   
    if (readInProgress) {
      inputBuffer[bytesRecvd] = x;
      bytesRecvd++;  //Data is still being read
      if (bytesRecvd == buffSize) { bytesRecvd = buffSize - 1; } //Prevent buffer overflow
    }  
    if (x == startMarker) { //Start marker received, begin reading
      bytesRecvd = 0;
      readInProgress = true;
    }
  }
}  

//Parse the received data from the buffer
void parseData() {
  char* strtokIndx;
  strtokIndx = strtok(inputBuffer, ",");  //Split the string by commas
  strcpy(messageFromPC, strtokIndx);      //Store the first token
  strtokIndx = strtok(NULL, ",");
  strtokIndx = strtok(NULL, ","); //Continue parsing if necessary
}

//Handle the picking process, with retries
void pick(short steps, byte Release) {PickupRetry = 0;
retrypickup:
  Move1(0, steps, zspeed);  //Move to pickup position
  if (Release == 1) {MotorsOnOff(1);delay(100);digitalWrite(Vacuum2,1);delay(300);digitalWrite(Vacuum2,0);ReadRange(3);  //Turn motors off and release card
    while ((range[2] + range[3]) / 2 < release_threshold) {digitalWrite(Vacuum2,1);delay(300);digitalWrite(Vacuum2,0);ReadRange(3);}//Check range and if card didn't drop retry
    MotorsOnOff(0);delay(100);Move1(1, steps, zespeed);} //Turn motors back on and move back up
  if (Release == 0) {digitalWrite(Vacuum1, 1);delay(500);digitalWrite(Vacuum1, 0);Move1(1, steps, zespeed);}ReadRange(3);//Vacuum to pick up card
    if (((range[2] + range[3]) / 2) > pickup_threshold) {PickupRetry++;if (PickupRetry >= 10) {StopMachine();} else {goto retrypickup;}}//If 10 retrys failed stop the machine
}  

//Homing routine to calibrate the machine
void Homemachine() {PrintLCD("Calibrating", " ");ReadEndstops();  //Read the endstop values
  if (Z_ENDSTOP_MIN == 1) {Move1(0, 800, zespeed);while (Z_ENDSTOP_MIN == 1) {Move1(1, 3, zespeed);Z_ENDSTOP_MIN = digitalRead(Zmin);}delay(200);}//calibrate z
  if (Y_ENDSTOP_MIN == 1) {Move4(1, 0, 0, 50);while (Y_ENDSTOP_MIN == 1) {Move4(0, 1, 0, 5);Y_ENDSTOP_MIN = digitalRead(Ymin);}delay(200);}//calibrate y
  if (X_ENDSTOP_MAX == 1) {Move4(1, 0, 50, 0);while (X_ENDSTOP_MAX == 1) {Move4(0, 1, 3, 0);X_ENDSTOP_MAX = digitalRead(Xmax);}delay(200);}//calibrate x
  Move1(0, 3000, zspeed); delay(200);Move4(1, 0, Xcal * 3 + 55, Ycal * 2 + 38); delay(200); //Move to home position
}  

void StopMachine() { //Stop the machine and display a message
  PrintLCD("Machine stop", "Empty and reset"); MotorsOnOff(0); while (1) { delay(10000);}
}

void ReadEndstops() { //Read the endstop sensors
  X_ENDSTOP_MIN = digitalRead(Xmin);X_ENDSTOP_MAX = digitalRead(Xmax);
  Y_ENDSTOP_MIN = digitalRead(Ymin);Y_ENDSTOP_MAX = digitalRead(Ymax);
  Z_ENDSTOP_MIN = digitalRead(Zmin);Z_ENDSTOP_MAX = digitalRead(Zmax);
}

void MotorsOnOff(boolean OnOff) { //Turns all motors on or off
  digitalWrite(Xenable, OnOff);digitalWrite(E0enable, OnOff);
  digitalWrite(Yenable, OnOff);digitalWrite(E1enable, OnOff);
  digitalWrite(Zenable, OnOff);
}

void DetermineAction() { //Figure out what to do
  for (int i = 0; i < sizeof(MatchingValues) / sizeof(MatchingValues[0]); ++i) {
    if (Tempval1 == MatchingValues[i]) {match = 1; ForLoop(loopStart[i], loopEnd[i]); break;}} // Handle specific matches
  if (Tempval1 == "CalibrateX1") {Move4(0,1,5,0); //Adjustments from python camera view
  } else if (Tempval1 == "CalibrateX2") {Move4(1,1,5,0);
  } else if (Tempval1 == "CalibrateY1") {Move4(0,0,0,5);
  } else if (Tempval1 == "CalibrateY2") {Move4(0,1,0,5);
  } else if (Tempval1 == "HomeButton") {Homemachine);
  
  } else if (match = 1){match = 0;}else{ForLoop(1, 34);} // Handle everything else
}

//Loop through trays and assign values accordingly
void ForLoop(byte first, byte last) {
  for (byte i = first; i <= last; i++) {
    if (AssignedTrayValue[i] == "") {AssignedTrayValue[i] = Tempval1;PrintLCD("Tray assigned ", Tempval1);delay(10);} //if tray assignment is empty assign it the received variable
    if (AssignedTrayValue[i] == Tempval1 && CountArray[i] <= 375) {Tray(i);Serial.println((String) "Went to tray" + i);break;} //if tray assignment equals received value go to that tray and break the loop
    else if (i == 34 && CountArray[34] < 375) {Tray(34);break;} //If loop reaches 34 go to tray 34 if less than 375 cards is in that tray
    else if (i == 34 && CountArray[34] >= 375) {StopMachine();Tempval1 = "";break;} //If loop reaches 34 and has 375 cards or more in it stop the machine
  }
}

//Function to handle the tray action based on the given tray number
void Tray(short var) {
  Move1(0, initial_pickup_distance, zspeed);ReadRange(1); //Move the Z-axis to the initial pickup position and read the range
  pick((range[0] + range[1]) / 2 * Zcal, 0);upcount++;CountArray[var]++; //Pick the card, Increment the total upcount and tray count
  short x, y;
  //Determine the X and Y coordinates based on the tray number
  for (byte j = 0; j < 6; j++) {if (X[j / 2][j % 4] == var) {x = xOffsets[j];break;}}
  for (byte j = 0; j < 4; j++) {if (Y[j][0] == var) {y = yOffsets[j];break;}}
  int absX = abs(Xcal * x);int absY = abs(Ycal * y);
  int moveToDirectionX =   (x >= 0) ? 1 : 0; int moveToDirectionY =   (y >= 0) ? 0 : 1; Move4(moveToDirectionX,   moveToDirectionY,   absX, absY); // Move to coordinate
  pick(initial_drop_distance, 1); ReadRange(5); while ((range[4] + range[5]) / 2 > 53) {Move1(1,5,zespeed);}
  int moveBackDirectionX = (x >= 0) ? 0 : 1; int moveBackDirectionY = (y >= 0) ? 1 : 0; Move4(moveBackDirectionX, moveBackDirectionY, absX, absY); // Move back to home tray
  Move1(1, initial_pickup_distance, zespeed); //Move Z back up to home position
  if (y != 0) { Move4(0, 0, 0, YCourseCorrection); } if (x != 0) { Move4(0, 1, XCourseCorrection, 0); } //Make course corrections if not 0
  if (upcount % HCC == 0 && upcount >= HCC / 2) { Homemachine(); } //If HCC count reached, rehome the machine
}

//Function to move in 4 directions based on the provided parameters
void Move4(boolean dir1, boolean dir3, short steps1, short steps2) {
  boolean dir2;
  if (dir1 == 0) {dir2 = 1;}else{dir2 = 0;}
  digitalWrite(Xdir, dir1); digitalWrite(E0dir, dir2); digitalWrite(Ydir, dir3); digitalWrite(E1dir, dir3);
  for (short i = 0; (i < steps1 || i < steps2); i++) { //Loop to move for the required number of steps in both directions
    if (i < steps1) {digitalWrite(Xstep, HIGH); digitalWrite(E0step, HIGH);}
    if (i < steps2) {digitalWrite(Ystep, HIGH); digitalWrite(E1step, HIGH);}
    delayMicroseconds(speed);
    digitalWrite(Xstep, LOW); digitalWrite(E0step, LOW); digitalWrite(Ystep, LOW); digitalWrite(E1step, LOW); //Deactivate step pins after each pulse
    delayMicroseconds(speed);
  }
}

//Function to move along the Z-axis with a specified direction and steps
void Move1(boolean dir, short steps, short speed1) {
  digitalWrite(Zdir, dir);
  for (short i = 0; i < steps; i++) { //Loop to perform the movement
    digitalWrite(Zstep, HIGH); delayMicroseconds(speed1);
    digitalWrite(Zstep,  LOW); delayMicroseconds(speed1);
  }
}

//Function to print a message to the LCD screen
void PrintLCD(String var1, String var2) {
  lcd.clear(); lcd.setCursor(0, 0); lcd.print(var1); lcd.setCursor(0, 1); lcd.print(var2);
}

//Function to read range values from the sensor
void ReadRange(byte var1) {
    range[var1 - 1] = vl.readRange(); delay(10); //Read range from sensor
    range[var1] = vl.readRange(); delay(10);//Read range from sensor
}

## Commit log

2025-04-13 Add files via upload
    Sample images from machine
2025-04-19 Update README.md
    Added 2020 visual construction, removed link to Tinkercad print files and added them directly to this repository
2025-04-19 Spacers for 2020 frame assembly
    [2.5mm spacer.stl, 5mm spacer.stl]
2025-04-19 Updated list
    Added additional options for 2020 frame design
2025-04-20 Added some assembly instructions
    Not finished
2025-05-02 Add files via upload
    Added more instructions and fixed some dead links in the materials list. Had to replace a pulley kit with individual items since the kit was no longer available.
2025-05-04 Add files via upload
    Edited to load any file matching default*.json, if you have multiple default json files it will select the newest one and print the total number of entries loaded
2025-05-23 Updated Z4 for shorter shoulder bolt availability
    [Z4 - Extension (130mm version).stl]
2025-05-25 Updated milled rod supplier
2025-05-28 Separated STLs and minor correction
    [Drill guide 1 (upper).stl, Drill guide 2 (upper).stl, Drill guide 3 (lower).stl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]
2025-06-01 Correction on rod placement
2025-06-01 Re-corrected rod placement, file didn't save
2025-06-13 **If using a din rail**
    These mounts support Arduino, Raspberry Pi, Relays (no longer applicable), the LCD screen, Power switch, and Vacuums
    [Power switch mount.stl, Universal din rail mount.stl, Vacuum mount.stl]
2025-06-15 For 2020 frame
    [2020 Drill guide 1.stl, 2020 Drill guide 2.stl, 2020 Drill guide 3.stl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]
2025-06-17 Fixed 200mm screw rod to 300mm screw rod, my bad
2025-06-19 External power switch option
    [Power switch case.stl]
2025-06-23 Rename Sample images.z01 to Sample images/Sample images.z01
2025-06-23 Rename Sample images.z02 to Sample images/Sample images.z02
2025-06-23 Rename Sample images.z03 to Sample images/Sample images.z03
2025-06-23 Rename Sample images.z04 to Sample images/Sample images.z04
2025-06-23 Rename Sample images.z05 to Sample images/Sample images.z05
2025-06-23 Rename Sample images.zip to Sample images/Sample images.zip
2025-06-23 More sorting
    [Wiring.ods]
2025-06-27 Correction on coupler
